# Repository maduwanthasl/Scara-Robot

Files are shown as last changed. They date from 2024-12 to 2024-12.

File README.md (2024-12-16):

# SCARA Robot (PRRR Configuration)

## 🌟 Overview  
This repository contains the design, build process, and control of a 4-DoF SCARA robot. The robot features a prismatic joint and three revolute joints (PRRR configuration) and is designed for precise pick-and-place tasks. It includes a functional GUI, real-time control, and an Arduino-based system for motor control.

<p align="center">
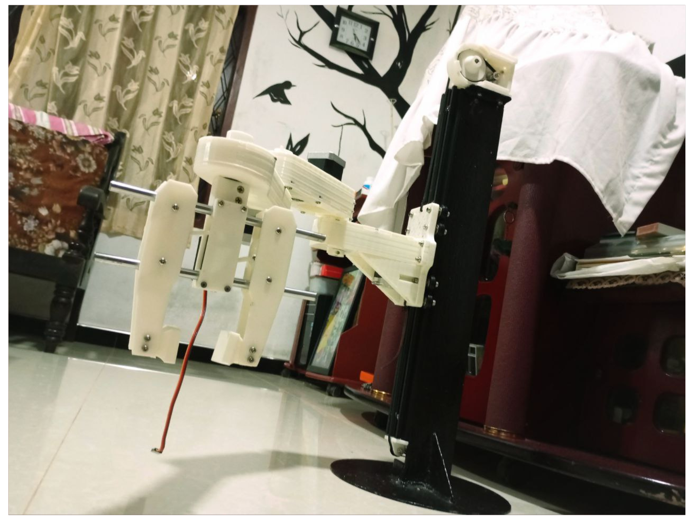
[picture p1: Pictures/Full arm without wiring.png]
  
</p>
<p align="center">
    <em>Figure 1: Final SCARA Robot</em>
</p>

---

## 📖 1. Introduction  
This project focuses on building and analyzing a **SCARA (PRRR)** robot arm with **4 Degrees of Freedom (DoF)**. It combines both kinematic analysis and practical implementation, including calculations for forward kinematics, inverse kinematics, and Jacobian analysis. The project culminates in a demonstration where the robot performs precise pick-and-place tasks and can **hold objects weighing up to 0.8 kg**.

**This SCARA robot is developed for industrial pick-and-place applications.**  
The manipulator consists of:  
- **A prismatic joint** for vertical motion.  
- **Three revolute joints** for horizontal movements and rotation.  
- **A gripper** for handling square and round objects.  

The robot is controlled using an Arduino Uno and stepper motors through a CNC shield. The GUI simplifies user interaction, making the robot versatile for various tasks.  

---

## 🎯 2. Final Outcome  
The SCARA robot successfully performs pick-and-place tasks with smooth motion and precise control.  

Video Preview (https://github.com/user-attachments/assets/54862c45-d594-4989-866d-df16e7200ece)

*Figure 2: Final Robot Outcome*  

---

## 🛠️ 3. Building Process  

### **3.1 Frame**  
In the SCARA robot building process, I first created a metal frame. I used a metal U-bar and a circular-shaped plate, soldering them as shown in Figure 3. To hold the Z-axis motor, I also soldered a plate. Afterward, I added screw holes to the grill and created two screw holes on the Z-holder plate. Additionally, I applied a coat of paint to resist metal corrosion.  

I also created screw holes in the U-bar to secure the aluminum extrusion. After that, I added a 40×20 aluminum extrusion to the U-bar using M5 20mm screws. This aluminum extrusion ensures smooth movement of the joints along the Z-axis.  

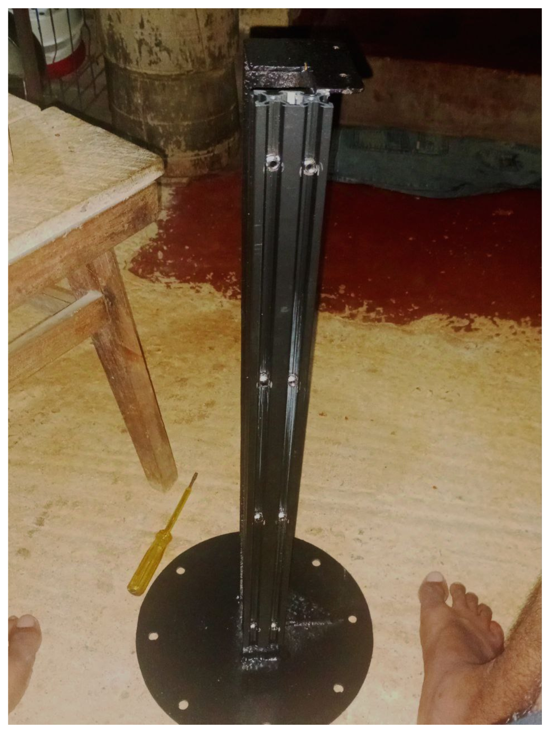
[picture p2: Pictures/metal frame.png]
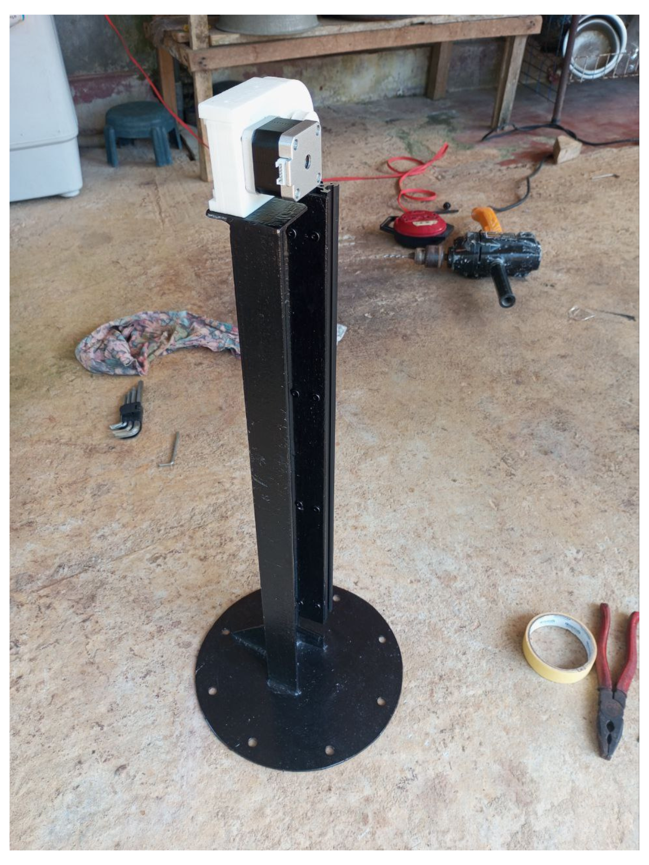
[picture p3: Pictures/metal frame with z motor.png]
|  |  |
|---|---|
| Metal frame | Metal frame with z motor|
<p align="center">
    <em>Figure 3: Metal Frame </em>
</p>

### **3.2 Joints**  

The joints of the SCARA robot are critical for achieving precise and smooth motion. Below is a detailed breakdown of the joint-building process.  

#### **3.2.1 3D Printed Parts**  
The main part of building this robot involved printing the 3D-printed components. Printing all the parts required over 100 hours using white PLA+ material. These parts included gears, mounting plates, and structural supports.  

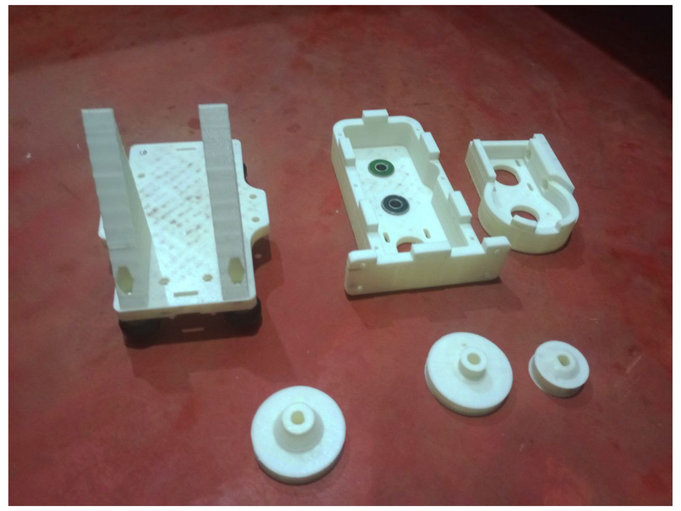
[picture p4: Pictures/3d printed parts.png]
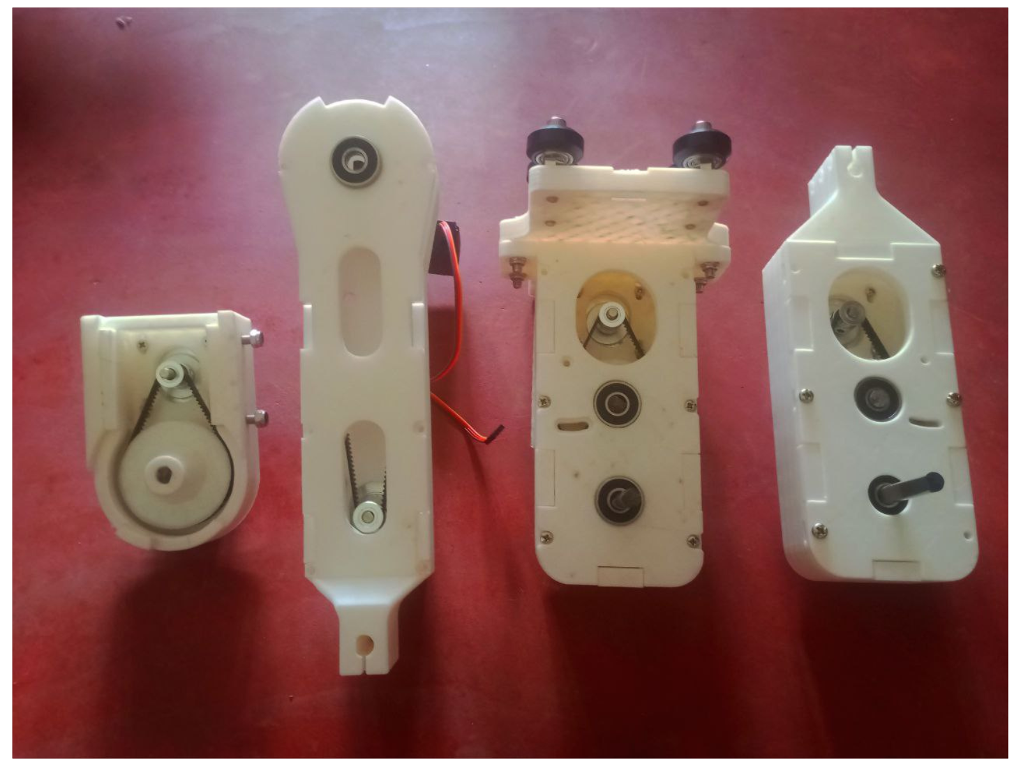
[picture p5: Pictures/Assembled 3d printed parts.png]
|  |  |
|---|---|
| Some 3D printed parts | Assembled Joints | 
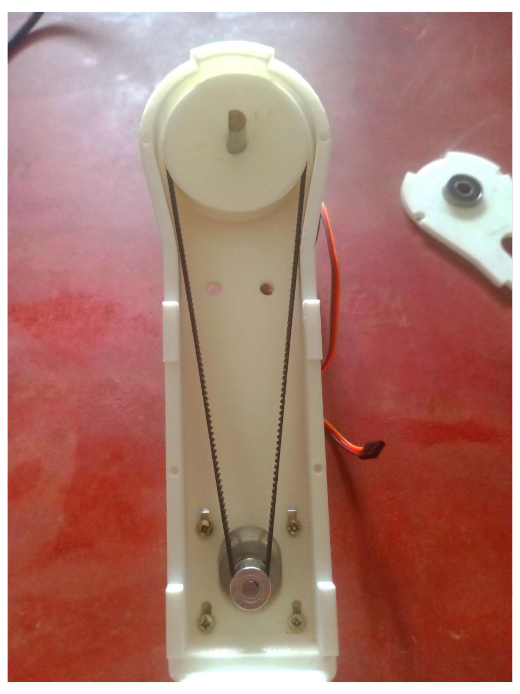
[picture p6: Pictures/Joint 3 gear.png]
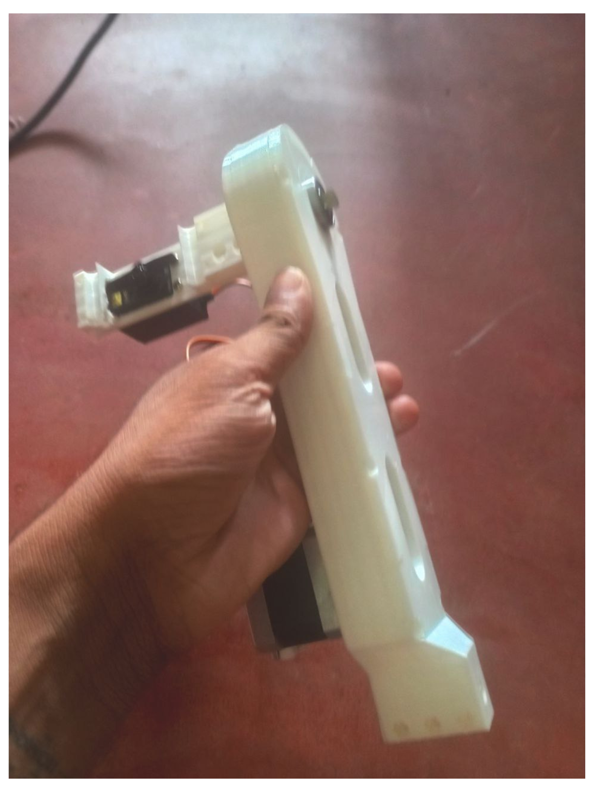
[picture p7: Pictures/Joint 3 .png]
|  | |
| Joint 3 Gears | Joint 3 Assembled |
<p align="center">
    <em>Figure 4: 3D printed parts </em>
</p>

#### **3.2.2 Linear Motion System**  
After printing the parts, I used 8mm diameter linear motion rods to construct the gear mechanism in the joints. To enhance torque, I incorporated 3D-printed gears into all joints. Most of the gear ratios were designed as 16:1, with some using a 4:1 ratio. These gears provided precise motion and controllable movements.  

To achieve smoother motion, I added 608RS bearings. For added friction with the gears, I modified small 8mm linear rods into a D shape using a grinder. By integrating suitable GT2 6mm closed-loop timing belts, the movement of the joints became more stable and reliable.  

Additionally, I added end-stop components made from 3D-printed parts. These help the robot identify when the arm has returned to its home position.  

#### **3.2.3 Challenges**  
The main challenge was ensuring that all belts were properly tightened and controllable to maintain smooth and precise motion throughout the joints.   

#### **3.2.4 Gripper Mechanism**  
The gripper is designed to handle objects of various shapes. It features a replaceable "hold cube" part that can be customized to grip different items. The gripper is powered by an MG 995 metal gear servo motor, which is well-suited for this type of application.  

#### **3.2.5 Sliding Mechanism**  
For the sliding mechanism, I attached a 3D-printed Z-plate to a **POM Wheel Pulley Kit**, which enabled smoother vertical motion. The Z-plate and pulley system significantly improved the performance of the prismatic joint.  

Video Preview (https://github.com/user-attachments/assets/a7ca6ed6-09e0-49c2-beae-47ccfda04f0f)

---

## 🔌 4. Wiring  

<p align="center">
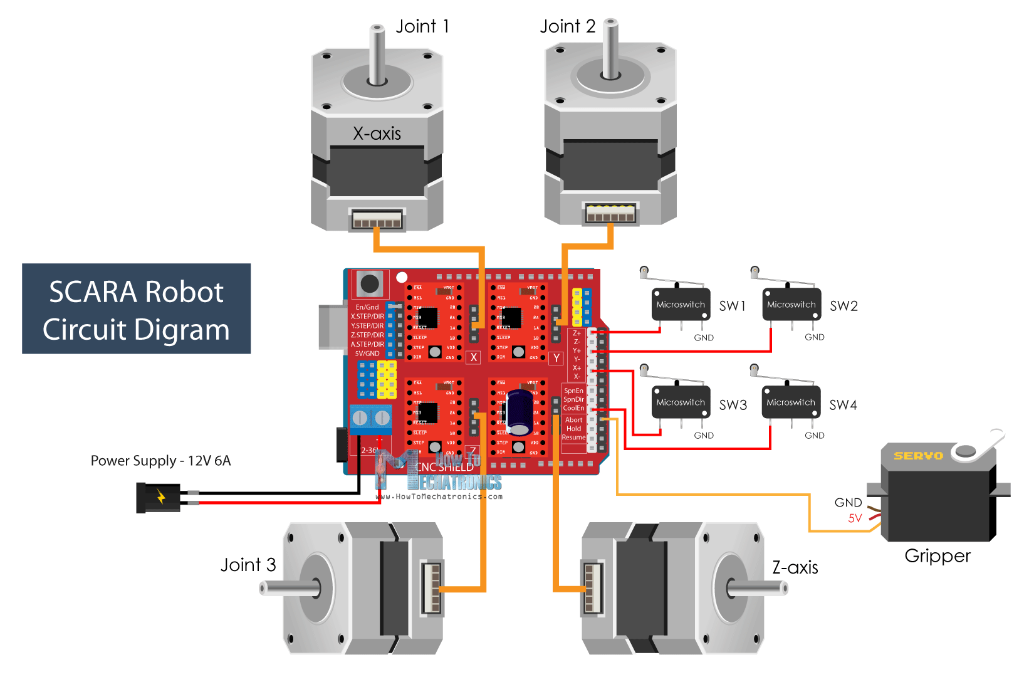
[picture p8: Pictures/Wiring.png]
  
</p>
<p align="center">
    <em>Figure 5: SCARA Robot main wiring diagram  </em>
</p>
<p align="center"> <em> Credit - how to mechatronics </em> </p>
 
The wiring connects stepper motors, the CNC shield, and the Arduino Uno. Here are the main considerations and steps followed:  

### **4.1 Motor Silence and Calibration**  
In wiring, I primarily focused on reducing motor noise. To achieve smooth motor operation, the current limit of the motor drivers was carefully adjusted. This calibration ensures precise motor activation. Setting an incorrect value can cause the motor drivers to overheat and potentially damage them. To further enhance motor precision, I adjusted the precision selector to 1/4 or 1/8 microstepping.

### **4.2 Connections and Testing**  
I connected the motor wiring as shown in the diagram and tested the connections with an oscilloscope and multimeter. Limit switches were placed at the corners of the joints' movement range to allow maximum rotational angles. After placing the limit switches, I assigned the pins for X+, Y+, Z+, and coolant functionalities.  

### **4.3 Servo Motor Powering**  
Since servo motors require a stable current, I initially tested them using the Arduino Uno with the CNC shield. However, the servo motor only received 3V from this setup, which was insufficient. To address this, I powered the servo motor separately using a 5V power supply.  

### **4.4 Power Supply Configuration**  
To power the entire system, which includes:  
- Four NEMA 17 stepper motors  
- Arduino Uno with CNC shield  
- Four motor drivers (DRV8825)  
- A servo motor  

I decided to use a 12V 10A power supply. A 12V 5A power supply would not have been sufficient to run all motors simultaneously.  

### **4.5 Cable Management**  
For clean and organized wiring, I used “Spiral Wire Wrapping Tube Cable Sleeves” and secured them with tie tags. This arrangement keeps the wires neat and minimizes clutter.  

### **4.6 Testing**  
To test all motors, I used simple Arduino code to verify their operation. This helped ensure that the motors, limit switches, and control pins were functioning as expected.  

### **4.7 Key Points**  
- **Shielded cables** were used for stepper motors to reduce electrical noise.  
- Correct polarity was ensured to avoid reversing motor directions.  
- The 12V DC power supply provided reliable power for the entire system.  

---

## 🏠 5. Homing Sequence
The homing sequence ensures that the robot starts from a known position:  

- The prismatic joint retracts to the lowest position.  
- Each revolute joint rotates to its home angle.  
- Limit switches provide feedback to confirm positions.  

As you can see in the video, the homing sequence begins with the gripper motor (joint 3). To determine the homing position, I used limit switches along with the following code:  

```cpp
void homing() {
  // Homing Stepper3
  while (digitalRead(limitSwitch3) != 1) {
    stepper3.setSpeed(-1100);
    stepper3.runSpeed();
    stepper3.setCurrentPosition(-1580); // When limit switch pressed set position to 0 steps
  }
  delay(20);

  stepper3.moveTo(0);
  while (stepper3.currentPosition() != 0) {
    stepper3.run();
  }

  // Homing Stepper2
  while (digitalRead(limitSwitch2) != 1) {
    stepper2.setSpeed(1300);
    stepper2.runSpeed();
    stepper2.setCurrentPosition(4350); // When limit switch pressed set position to -5440 steps
  }
  delay(20);

  stepper2.moveTo(0);
  while (stepper2.currentPosition() != 0) {
    stepper2.run();
  }

  // Homing Stepper1
  while (digitalRead(limitSwitch1) != 1) {
    stepper1.setSpeed(-1200);
    stepper1.runSpeed();
    stepper1.setCurrentPosition(-5000); // When limit switch pressed set position to 0 steps
  }
  delay(20);
  stepper1.moveTo(0);
  while (stepper1.currentPosition() != 0) {
    stepper1.run();
  }
  // Homing Stepper4
  while (digitalRead(limitSwitch4) != 1) {
    stepper4.setSpeed(-1500);
    stepper4.runSpeed();
    stepper4.setCurrentPosition(-8500); // When limit switch pressed set position to 0 steps
  }
  delay(20);
  // stepper4.moveTo(0);
  while (stepper4.currentPosition() != 0) {
    stepper4.run();
  }
}
```
**Homing** - https://github.com/maduwanthasl/Scara-Robot/blob/main/Videos/Homing%20Function/Homing%20Function.mp4

---

## 🧩 6. Pick and Place Application
The robot is programmed to pick objects from a defined source and place them in a target location.  

- Move to the pick position using the prismatic and revolute joints.  
- Grip the object using the servo-controlled gripper.  
- Transition to the target location and release the object.  

In the pick-and-place application, I saved 8 waypoints starting from its home position. Using the GUI, I configured these waypoints, which helped to better understand the movement of the joints and the gripper. After saving the waypoints and running the sequence, I achieved the following output:  

**Pick and Place Output** - https://github.com/maduwanthasl/Scara-Robot/blob/main/Videos/Pick%20and%20place/Pick%20and%20place.mp4

---

## 🖥️ 7. GUI  

<p align="center">
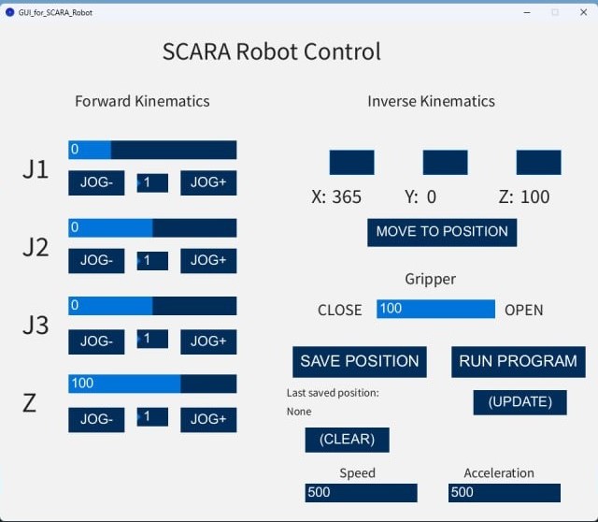
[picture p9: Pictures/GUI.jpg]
  
</p>

A user-friendly GUI is developed using **Processing**.  

### **Features**  
- Joint control via sliders and buttons.  
- Position control for end-effector coordinates.  
- Real-time feedback for joint angles and positions.  
- Gripper control for opening/closing actions.    

---

## 🛒 8. Bill of Materials  

---

### Purchase Details  
| **Buying Stores** | **Payable To** | **Invoice ** | **Date** |  
|---|---|---|---|
| Zenix | 11,890 | | |  
| Tronic LK | | | |  
| Asian | | | |  
| Unitech | | | |  

---

### Itemized List of Components  
| **Description** | **Qty** | **Unit Price** | **Total Price** |  
|---|---|---|---|
| 17HS4401 NEMA 17 Stepper with wire 0.4Nm (D Shaft 5mm) | 1 | Rs. 2,300.00 | Rs. 2,300.00 |  
| 2040 V Slot Aluminium Extrusion Profile Black 1m (Basic Quality) - Length (mm): 1000mm | 1 | Rs. 3,900.00 | Rs. 3,900.00 |  
| GT2 (Brown Anti-Slip Toothed Cloth, Rubber with Fiberglass) 6mm Open Timing Belt 1m | 2 | Rs. 350.00 | Rs. 700.00 |  
| GT2 16T 16 Teeth 5mm Bore 6mm Width Timing Pulley T16B5W6 - Color: Silver | 1 | Rs. 120.00 | Rs. 120.00 |  
| GT2 20T 20 Teeth 5mm Bore 6mm Width Timing Pulley T20B5W6 - Color: Silver | 3 | Rs. 120.00 | Rs. 360.00 |  
| GT2 20T 20 Teeth 8mm Bore 6mm Width Timing Pulley T20B8W6 - Color: Silver | 1 | Rs. 120.00 | Rs. 120.00 |  
| GT2 6mm Closed Loop Timing Belt 200mm | 5 | Rs. 190.00 | Rs. 950.00 |  
| GT2 6mm Closed Loop Timing Belt 400mm | 2 | Rs. 280.00 | Rs. 560.00 |  
| Openbuilds (Type A2 with Eccentric Spacer) POM Wheel Pulley Kit for 2020 V Slot Aluminum Profiles | 8 | Rs. 360.00 | Rs. 2,880.00 |  
| 17HS4401 NEMA 17 Stepper with wire 0.4Nm (D Shaft 5mm) | 3 | Rs. 2,300.00 | Rs. 4,600.00 |  
| CNC Shield V3 Expansion Board for Engraving Machine | 1 | Rs. 490.00 | Rs. 490.00 |  
| 8mm Insulated Braided Sleeve High Temperature Tube 1m | 1 | Rs. 120.00 | Rs. 120.00 |  
| GT2 16T 16 Teeth 5mm Bore 10mm Width Timing Pulley T16B5W10 | 1 | Rs. 160.00 | Rs. 160.00 |  
| GT2 20T (With Teeth) 5mm Bore 6mm Width Idler Timing Pulley B5W6 - Color: Black | 1 | Rs. 260.00 | Rs. 260.00 |  
| GT2 16T 16 Teeth 5mm Bore 6mm Width Timing Pulley T16B5W6 - Color: Silver | 2 | Rs. 120.00 | Rs. 240.00 |  
| Arduino UNO Original Development | 1 | Rs. 2,510.00 | Rs. 2,510.00 |  
| DRV8825 Stepper Motor Driver for CNC 3D Printer | 4 | Rs. 520.00 | Rs. 2,080.00 |  
| Cable Tie 15-inch 100 pcs | 1 | Rs. 300.00 | Rs. 300.00 |  
| M5 35mm Stainless Steel Hex Flat Socket Head Countersunk Screw | 12 | Rs. 70.00 | Rs. 840.00 |  
| M5 16mm Stainless Steel Hex Flat Socket Head Countersunk Screw | 6 | Rs. 40.00 | Rs. 240.00 |  
| M3 20mm Countersunk Bolt | 12 | Rs. 5.00 | Rs. 60.00 |  
| M4 15mm Countersunk Bolt | 18 | Rs. 10.00 | Rs. 180.00 |  
| Black 10mm 1 Bag (13.5m/Bag) Spiral Wire Wrapping Tube Cable Sleeves | 1 | Rs. 800.00 | Rs. 800.00 |  
| 12V 10A Power Supply | 1 | Rs. 2,200.00 | Rs. 2,200.00 |  
| Jumper Cables | 1 | Rs. 140.00 | Rs. 140.00 | 
| Bearing 608-RS			 | 15	 | Rs.400	 | Rs.6,000.00 |
| 8mm Leaniar Rob			 |1	 | $1,500	| $1,500.00 |
| Other | 1 | Rs. 2,000.00 | Rs. 2,000.00 |  

---

### **Total Cost**  
| **Subtotal** | Rs. 36,610.00 |  
|---|---|
| **Adjustments** | Rs. 0.00 |  
| **Final Total** | **Rs. 36,610.00** |  

---

## 🖨️ 9. 3D Printed Parts

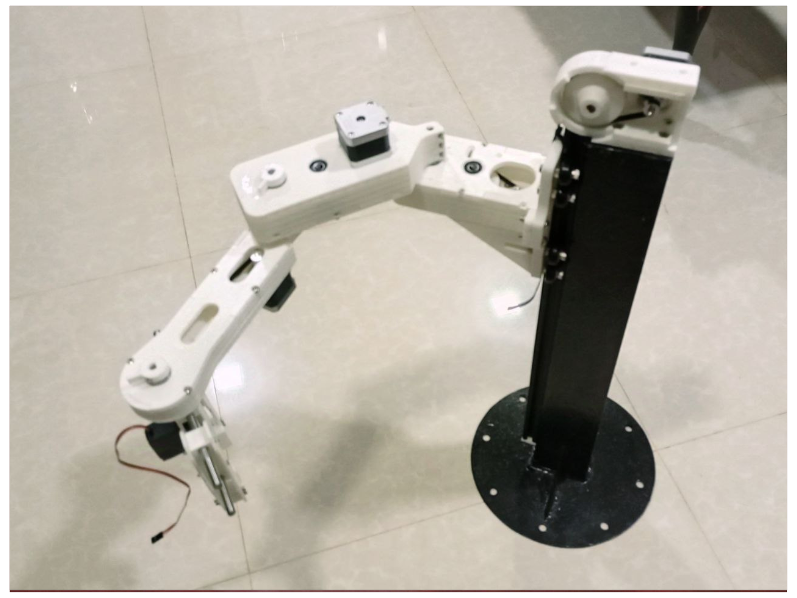
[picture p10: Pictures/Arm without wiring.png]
| pic 6 (2) |  |
|---|---|
<p align="center">
    <em>Figure 6: ARM without wiring </em>
</p>

The robot's design relies heavily on 3D-printed components, with over 100 hours of printing time invested to produce these parts. Each part was carefully designed to ensure functionality and precision:  

- **Gears**: Over seven different types of gears were printed to enable precise torque transfer and smooth motion across the joints.  
- **Link Components**: Critical parts for Link 1, Link 2, and Link 3 were printed to form the main structure of the robotic arm, allowing for stable and accurate joint movements.  
- **Z Holder**: This component supports the prismatic joint, ensuring reliable vertical motion and alignment.  
- **Limit Switch Contactors**: Custom 3D-printed parts that interact with limit switches to facilitate homing and accurate position detection.  
- **Gripper Mechanism**: Includes the gripping claws and structural supports necessary for securely holding objects during operation.  
- **Support Structures**: Temporary structures were printed alongside the main components to maintain the integrity of complex shapes during the printing process.  

These parts were printed using PLA+ material for durability and dimensional accuracy. All STL files are organized and available in the `/3D-Printed-Parts` folder for easy access and replication.  

---

## 🔗 10. Code Explanation
The robot is programmed using Arduino Uno, with future plans to transition to AVR register-based programming for enhanced control. The key programming aspects include:  

- **Forward Kinematics**: Calculates the end-effector position based on joint values, ensuring precise movement to desired coordinates.  
- **Inverse Kinematics**: Determines joint angles for a given position, enabling accurate trajectory planning for the robot arm.  
- **DH Table and Jacobian Matrix**: The Denavit-Hartenberg (DH) parameters were derived to construct the transformation matrix, while the manipulator Jacobian was calculated to analyze joint velocities and forces.  
- **Control Algorithms**: Implements control for stepper motors, including speed adjustments and precise motion handling.  
- **Gripper Control**: Manages the servo-controlled gripper to open and close efficiently based on commands.  

To facilitate communication between the computer and the Arduino Uno, serial communication was established at a baud rate of 115200. This allows for easy command input and real-time control without needing to manually alter the code for each operation.  

Future iterations will focus on optimizing the code and exploring advanced microcontroller programming techniques for better performance.  

---

## 🎛️  11. Robot Details and Calculations

### **11.1 Link Dimensions and Specifications**  
The SCARA robot has **4 Degrees of Freedom (DoF)** with a **PRRR joint configuration**.  

**Link Dimensions**:  
- a1 = 160mm — Link 1 length  
- a2 = 220mm — Link 2 length  
- a3 = 202mm — Link 3 length  
- d4 = 580mm — Prismatic joint length  

### **11.2 Coordinate Frame Assignment**  
The following figure illustrates the coordinate frame assignment for the SCARA PRRR robot, adhering to the Denavit-Hartenberg (DH) convention:  

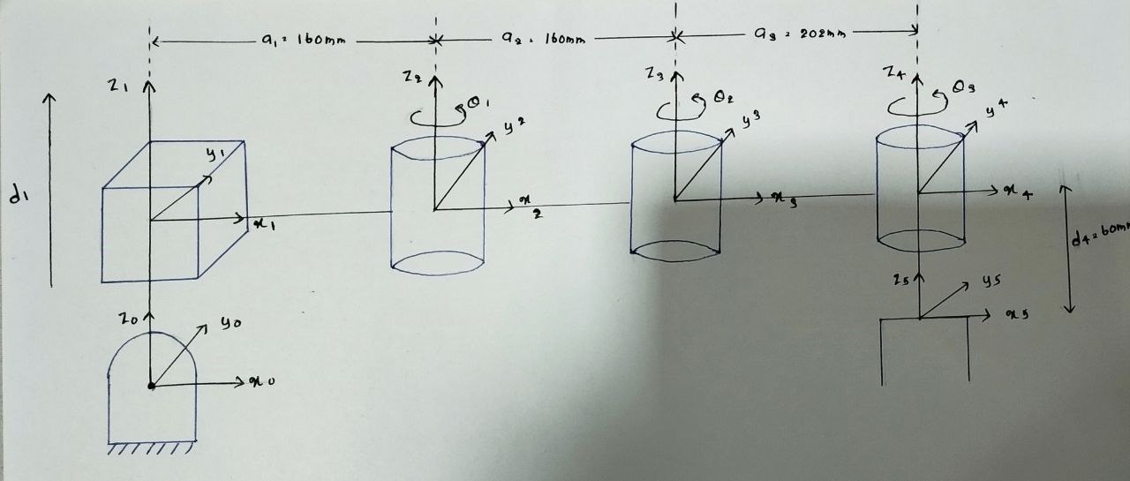
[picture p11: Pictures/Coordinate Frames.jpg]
Coordinate Frame Assignment
  

### **11.3 DH Table**  
The table below summarizes the DH parameters for the SCARA PRRR robot:  

| **Joint (i)** | **aᵢ (mm)** | **αᵢ (°)** | **dᵢ (mm)** | **θᵢ (°)** |
|---|---|---|---|---|
| 1 (Prismatic) | 0 | 0 | d₁ (variable) | 0 |
| 2 (Revolute) | 160 | 0 | 0 | θ₁ (variable) |
| 3 (Revolute) | 160 | 0 | 0 | θ₂ (variable) |
| 4 (Revolute) | 202 | 0 | 0 | θ₃ (variable) |
| 5 | 0 | 0 | 580 | 0 |

### **11.4Forward Kinematics**

Forward kinematics calculates the position and orientation of the end-effector based on the joint angles and link lengths. Using Denavit-Hartenberg (DH) parameters, we define the transformation matrix for each joint. The transformation matrix is:

<p align="center">
  SCARA Robot
</p>
By multiplying the individual transformation matrices from base to end-effector, we get the final transformation matrix T . This matrix provides the position (x, y, z) and the orientation of the end-effector. The angles θ1, θ2, and θ3 are used to determine the robot’s orientation in space.

<p align="center">
  SCARA Robot
</p>

<p align="center">
  SCARA Robot
</p>

The Jacobian is derived using the partial derivatives of the forward kinematics equations.  

### **11.5Manipulator Jacobian Matrix**
The Jacobian matrix relates joint velocities to end-effector velocities. It is essential for analyzing the robot’s motion and controlling its speed and acceleration. For a PRRR manipulator, the Jacobianmatrix has two parts:

- Linear Velocity: The part of the Jacobian that maps joint velocities to linear velocities of the end-effector. It involves the cross product between the joint axes and the position vector.
- Angular Velocity: The part that maps joint velocities to angular velocities.

The Jacobian for the SCARA robot is given by:

<p align="center">
  SCARA Robot
</p>

---

## 📶 12. Gallery  
The gallery showcases the various stages of the robot's development, including 3D-printed parts, wiring, assembly, and testing.

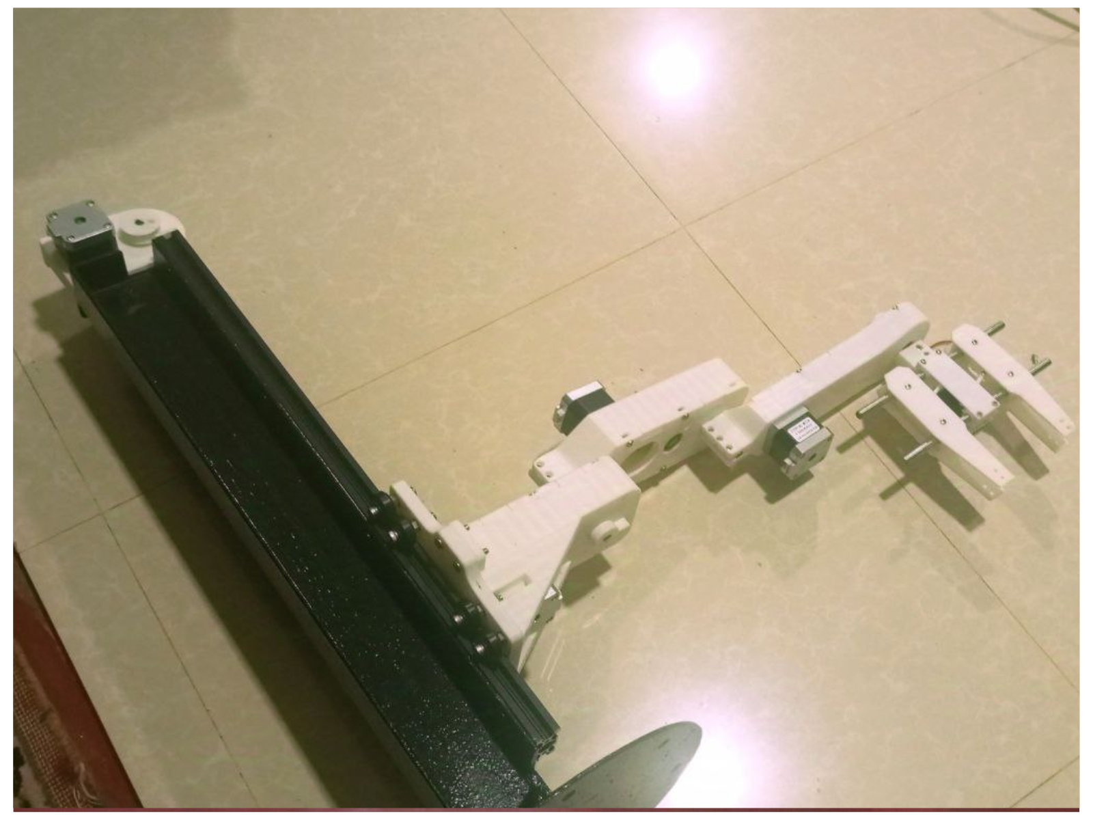
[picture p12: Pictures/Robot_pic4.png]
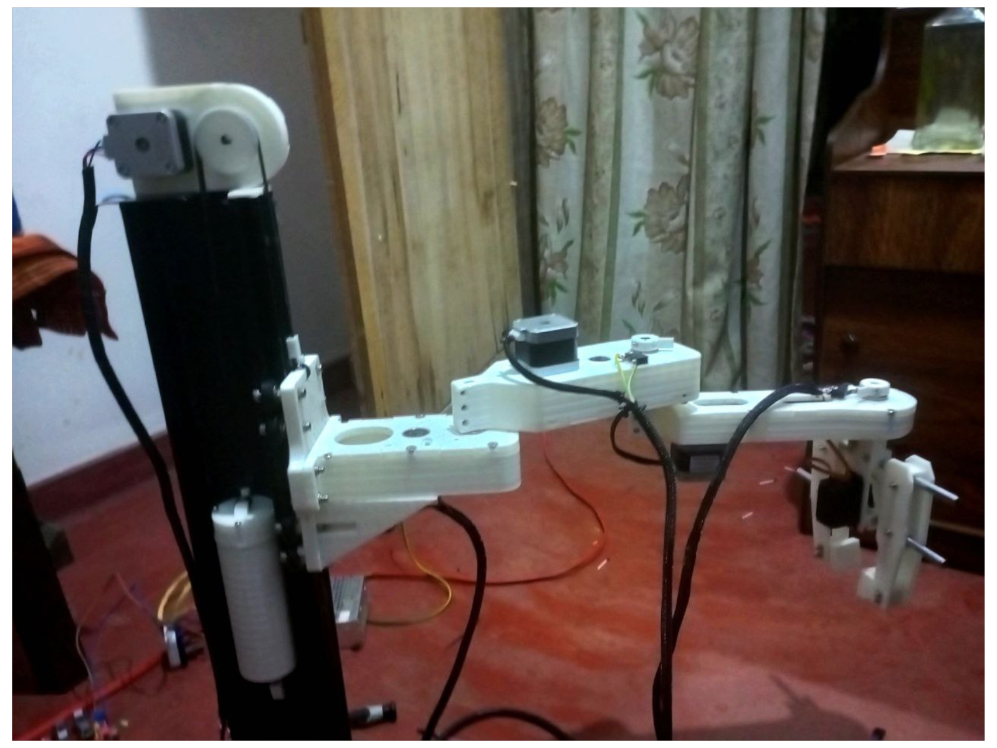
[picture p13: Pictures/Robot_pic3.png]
|  |  |
|---|---|
| Adding All Joints | Adding wiring | 
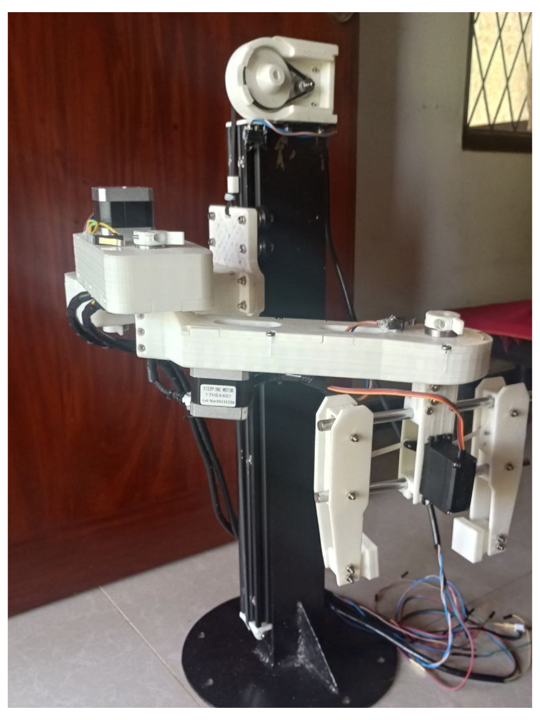
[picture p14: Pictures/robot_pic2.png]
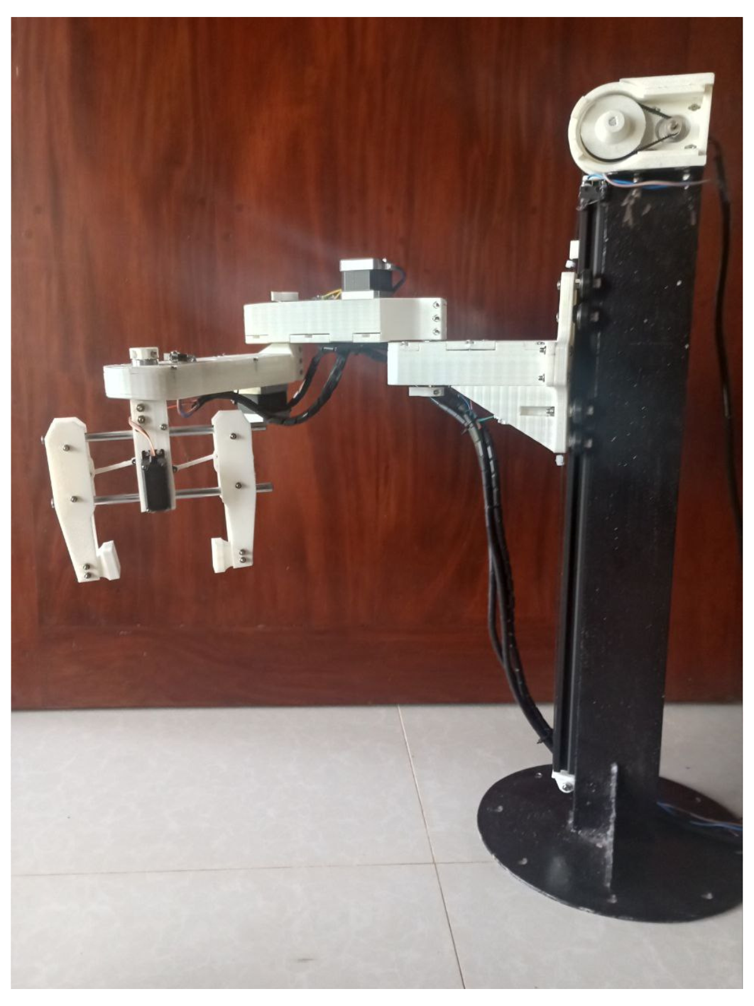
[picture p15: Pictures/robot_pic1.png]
|  | |
| Angle 1 | Angle 2 |
<p align="center">
    <em>Figure 7: Build Journey</em>
</p>

---
## 🤖 13. References  
- SCARA Robot Design Basics: [Link](https://en.wikipedia.org/wiki/SCARA)  
- Arduino CNC Shield Documentation: [Link](https://www.aranacorp.com/en/using-an-arduino-cnc-shield-v3)  
- Processing Language for GUI: [Link](https://howtomechatronics.com/projects/scara-robot-how-to-build-your-own-arduino-based-robot)
- Scara Robot 3D Printed Parts: [Link](https://github.com/IVProjects/Engineering_Projects/tree/main/ProjectFiles/SCARA%20Robot)
  
---

Feel free to raise issues or contribute improvements to this project!

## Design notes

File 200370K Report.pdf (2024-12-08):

Department of Electronic & Telecommunication Engineering, University of Moratuwa, Sri Lanka.

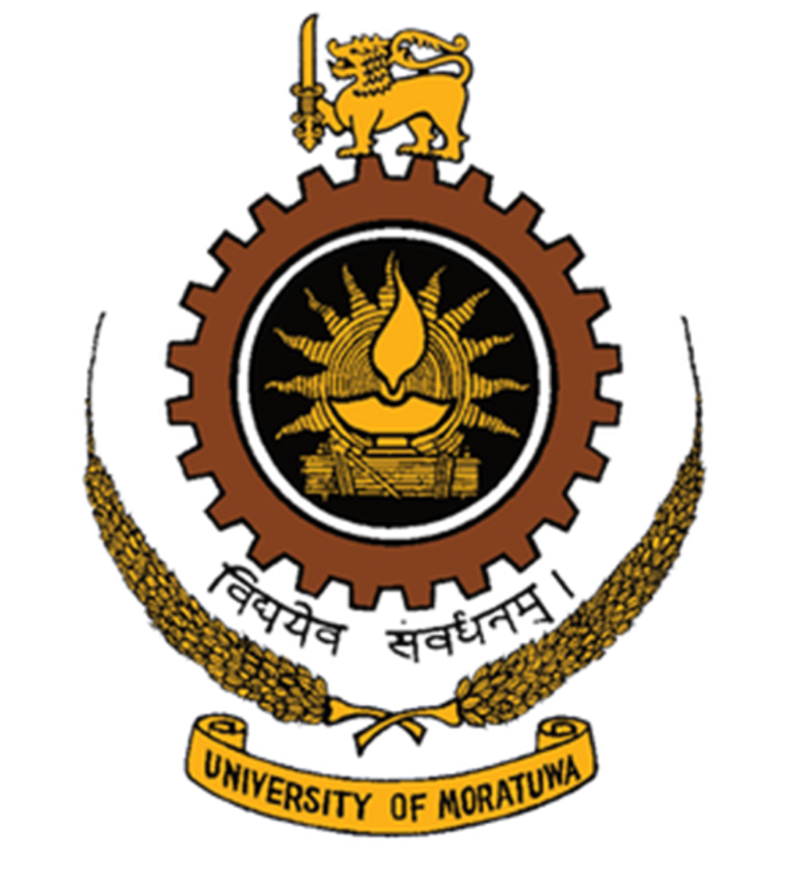
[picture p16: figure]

# Robotics Mini Project Kinematic Analysis of a Robot Arm

Maduwantha L.H.H | 200370K

## Summarizing the analysis - Report In21 S5 EN3563 - Robotics

08th December 2024

EN 2160 Electronics Design Realization

## Introduction

This mini-project focuses on the kinematic analysis of a SCARA robot with four degrees of freedom (DoF). The robot has a prismatic joint (for vertical movement) and three revolute joints (for horizontal rotation), allowing it to perform pick-and-place tasks. A functional gripper is included to handle round and square objects.

Analysis

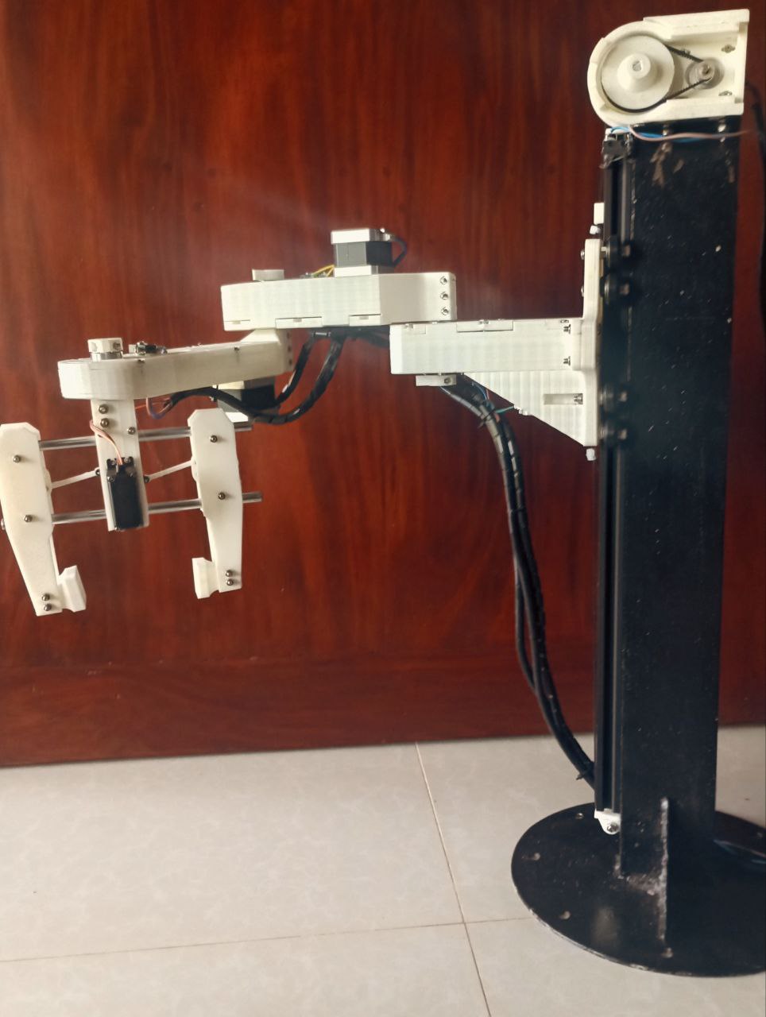
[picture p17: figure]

The analysis includes:
- Deriving Denavit-Hartenberg (DH) parameters.
- Calculating forward and inverse kinematics.
- Deriving the Jacobian matrix.

Control and Payload

The robot is controlled using an Arduino Uno and stepper motors via a CNC shield. It has a maximum payload of 0.8 kg.

1

## Robot Design and DH Parameters

Robot Configuration

The robot arm consists of the following links and joints:
- a1 = 160 mm, a2 = 160 mm, a3 = 202 mm: These are the link lengths between the revolute joints.
- d1 (variable): Vertical movement of the prismatic joint.
- d4 = 60 mm: Constant offset for the final joint.
- θ1, θ2, θ3: The joint angles that control the robot’s movement in the horizontal plane.

Scara Robot - Coordinate Frame assignment


Denavit-Hartenberg Parameters

The Denavit-Hartenberg (DH) parameters describe the geometry of the robot arm through a systematic convention. The table below shows the DH parameters for the SCARA robot:

Joint (i) | ai (mm) | αi | di (mm) | θi
1 (Prismatic) | 0 | 0 | d1 (variable) | 0
2 (Revolute) | 160 | 0 | 0 | θ1 (variable)
3 (Revolute) | 160 | 0 | 0 | θ2 (variable)
4 (Revolute) | 202 | 0 | 0 | θ3 (variable)
5 | 0 | 0 | 60 | 0

Table 1: DH Parameters for the SCARA Robot

This DH table is crucial for calculating the forward and inverse kinematics.

## Forward Kinematics

Forward kinematics calculates the position and orientation of the end-effector based on the joint angles and link lengths. Using Denavit-Hartenberg (DH) parameters, we define the transformation matrix for each joint. The transformation matrix is:

2

T

i
i−1 =

cos θi | − sin θi cos αi | sin θi sin αi | ai cos θi
sin θi | cos θi cos αi | − cos θi sin αi | ai sin θi
0 | sin αi | cos αi | di
0 | 0 | 0 | 1

By multiplying the individual transformation matrices from base to end-effector, we get the final transformation matrix T

4/0. This matrix provides the position (x, y, z) and the orientation of the end-effector. The angles θ1, θ2, and θ3 are used to determine the robot’s orientation in space.

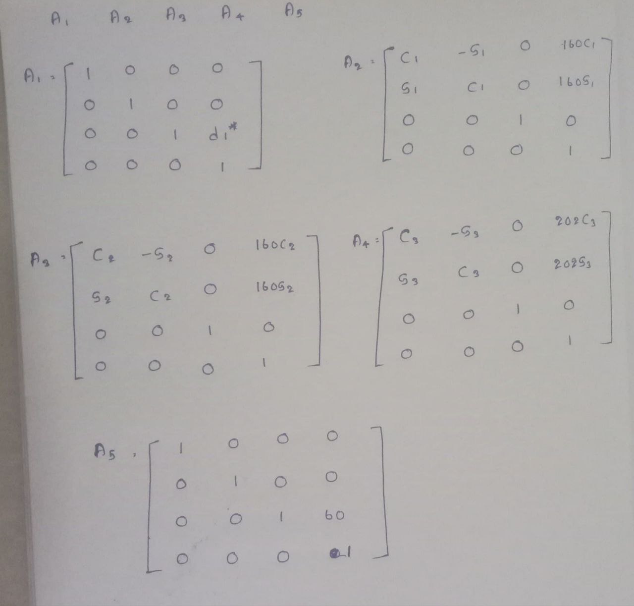
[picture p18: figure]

End-Effector Position

Using the link lengths and joint angles, the position of the end-effector is calculated as:

x = a1 sin(90◦
) + a2 cos θ1 + a3 cos(θ1 + θ2)

x = 160 + 160 cos θ1 + 202 cos(θ1 + θ2)

y = a1 cos(90◦
) + a2 sin θ1 + a3 sin(θ1 + θ2)

y = 0 + 160 sin θ1 + 202 sin(θ1 + θ2)

z = z0 + d1

## Inverse Kinematics

Inverse kinematics is the process of solving for the joint variables (θ1, θ2, θ3, d0) given a desired position and orientation of the end-effector. For the SCARA robot, the inverse kinematics is separated into two primary steps:

3

Step 1: Solve for θ1, θ2, θ3

Using the planar geometry of the robot, we can calculate the joint angles. The horizontal position of the end-effector is given by:

x = a1 + a2 cos(θ1) + a3 cos(θ1 + θ2)

y = a2 sin(θ1) + a3 sin(θ1 + θ2)

The law of cosines is applied to solve for θ2 and θ3 iteratively:

cos θ2 =

r

2 − a

2
2 − a

2
3
2a3a2

Once θ2 is computed, θ1 is found by solving for the orientation of the base using inverse trigonometry:
θ1 = arctan y
x

− arctan
a3 sin θ2
a2 + a3 cos θ2

Finally, θ3 is derived by using the desired end-effector orientation.

Step 2: Solve for d0

The vertical position is determined by the prismatic joint:

d1 = z − d4

## Jacobian Matrix

The Jacobian matrix relates joint velocities to end-effector velocities. It is essential for analyzing the robot’s motion and controlling its speed and acceleration. For a PRRR manipulator, the Jacobian matrix has two parts:

- Linear Velocity: The part of the Jacobian that maps joint velocities to linear velocities of the end-effector. It involves the cross product between the joint axes and the position vector.
- Angular Velocity: The part that maps joint velocities to angular velocities.

The Jacobian for the SCARA robot is given by:

J =

Jv
Jω

Where:

- Jv is the linear velocity Jacobian, accounting for the prismatic and revolute joints.
- Jω is the angular velocity Jacobian, accounting for revolute joints.

J =

(z

o
0

) z

o
1
- (t

o
4 − ti) z

o
2
- (t

o
4 − t

o
2

) z

o
3
- (t4 − t

o
3

)
0 | z

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
0 J12 | J13 | J14
0 J22 | J23 | J24
1 J32 | J33 | J34
0 | 0 | 0 | 0
0 | 0 | 0 | 0
0 | 1 | 1 | 1

4

## Graphical User Interface (GUI)

The GUI allows users to control the SCARA robot with ease. It was developed using Processing and communicates with the robot via an Arduino Uno.


Key Features

- Joint Control:
Sliders and buttons enable precise movement of the robot’s joints (θ1, θ2, θ3, d1).
- Position Control:
Users can input the desired end-effector positions, and the robot calculates the corresponding joint angles.
- Gripper Control:
Buttons are provided to open and close the gripper for handling objects.
- Real-time Feedback:
The interface displays the current position and status of the robot in real time.

## Reference

- IVProjects GitHub (https://github.com/IVProjects) - *Engineering Projects*

5

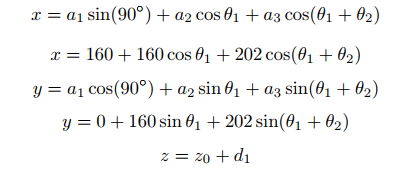
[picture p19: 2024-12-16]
Pictures/Forard kinematics.png

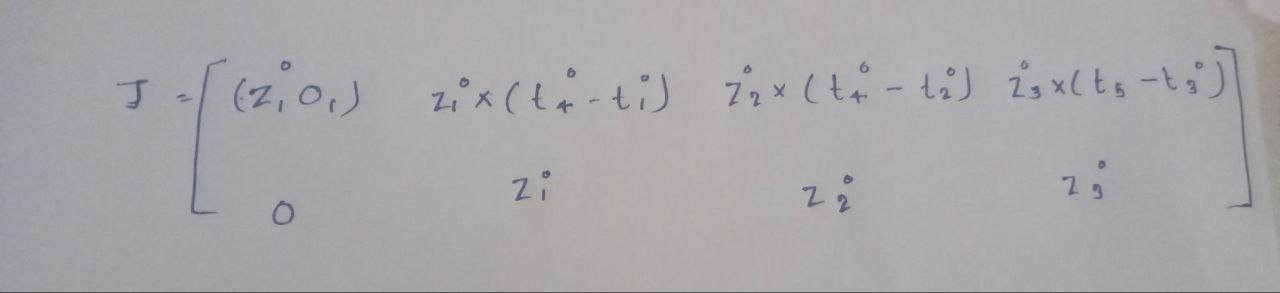
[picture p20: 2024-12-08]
Pictures/Manipulator Jacobian.jpg

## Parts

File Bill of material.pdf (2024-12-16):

# Scara Robot Design

Hirusha Madhuwantha
(+94) 741270399

# Bill of Materials

Submitted on 09/10/2024

Buying stores | Payable to | Invoice # | Date
zenix | 11,890 | #IN002095 | 2024-09-09

tronic lk

Asian

Unitech

Description | Qty | Unit price | Total price

17HS4401 NEMA 17 Stepper with wire 0.4Nm (D Shaft 5mm) 1 $2,300.00 $2,300.00

2040 V Slot Aluminium Extrusion Profile Black 1m (Basic Quality) -$3,900.00 Length (mm) : 1000mm 1 $3,900.00

GT2 (Brown Anti-Slip Toothed Cloth, Rubber with Fiberglass) 6mm Open 2 $700.00 $350.00 Timing Belt 1m

GT2 16T 16 Teeth 5mm Bore 6mm $120.00 Width Timing Pulley T16B5W6 -Color : Silver 1 $120.00

GT2 20T 20 Teeth 5mm Bore 6mm
Width Timing Pulley T20B5W6 -
Color : Silver | 3 | $120.00

$360.00

GT2 20T 20 Teeth 8mm Bore 6mm $120.00 Width Timing Pulley T20B8W6 -1 Color : Silver $120.00

GT2 6mm Closed Loop Timing Belt 200mm 5 $190.00 $950.00

GT2 6mm Closed Loop Timing Belt 400mm 2 $280.00 $560.00

Openbuilds (Type A2 with Eccentric Spacer) POM Wheel Pulley Kit for 2020 V Slot Aluminum Profiles 8 $360.00 $2,880.00

17HS4401 NEMA 17 Stepper with wire 0.4Nm (D Shaft 5mm) 3 $2,300.00 $4,600.00

CNC Shield V3 Expansion Board for Engraving Machine 1 $490.00 $490.00

8mm Insulated Braided Sleeve High Temperature Tube 1m 1 $120.00 $120.00

GT2 16T 16 Teeth 5mm Bore 10mm Width Timing Pulley T16B5W10 1 $160.00 $160.00

GT2 20T (With Teeth) 5mm Bore 6mm Width Idler Timing Pulley B5W6 - Color: Black 1 $260.00 $260.00

GT2 16T 16 Teeth 5mm Bore 6mm Width Timing Pulley T16B5W6 - Color: Silver 2 $120.00 $240.00

Arduino UNO Original Development | 1 $2,510.00 $2,510.00
DRV8825 Stepper Motor Driver for CNC 3D Printer | 4 | $520.00 | $2,080.00
Cable Tie 15-inch 100 pics | 1 $300.00 $300.00
M5 35mm Stainless Steel Hex Flat Socket Head Countersunk Screw 12 M5 16mm Stainless Steel Hex Flat Socket Head Countersunk Screw 6 M3 20mm Countersunk Bolt M4 15mm Countersunk Bolt Black 10mm 1 Bag (13.5m/Bag) Spiral Wire Wrapping Tube Cable Sleeves 1 | $70 $40 12 $5 18 $10 $800 | $840.00 $240.00 $60.00 $180.00 $800.00
12V 10A power supply 1 $2,200 | | $2,200.00

Jumper cables

| 1 | $140 | $140.00
Bearing 608-RS | 15 | $400 | $6,000.00

8mm Leaniar Rob

| 1 | $1,500 | $1,500.00
Other | 1 | $2,000 | $2,000.00
Notes: | | Subtotal | $36,610.00
| | Adjustments | $0.00
$36,610.00

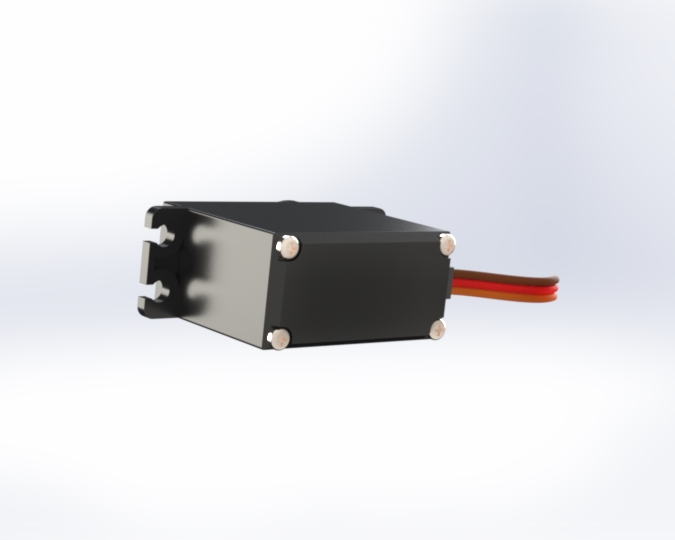
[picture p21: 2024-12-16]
3D printed parts/mg995-servo-3.snapshot.4/MG995 2.jpg

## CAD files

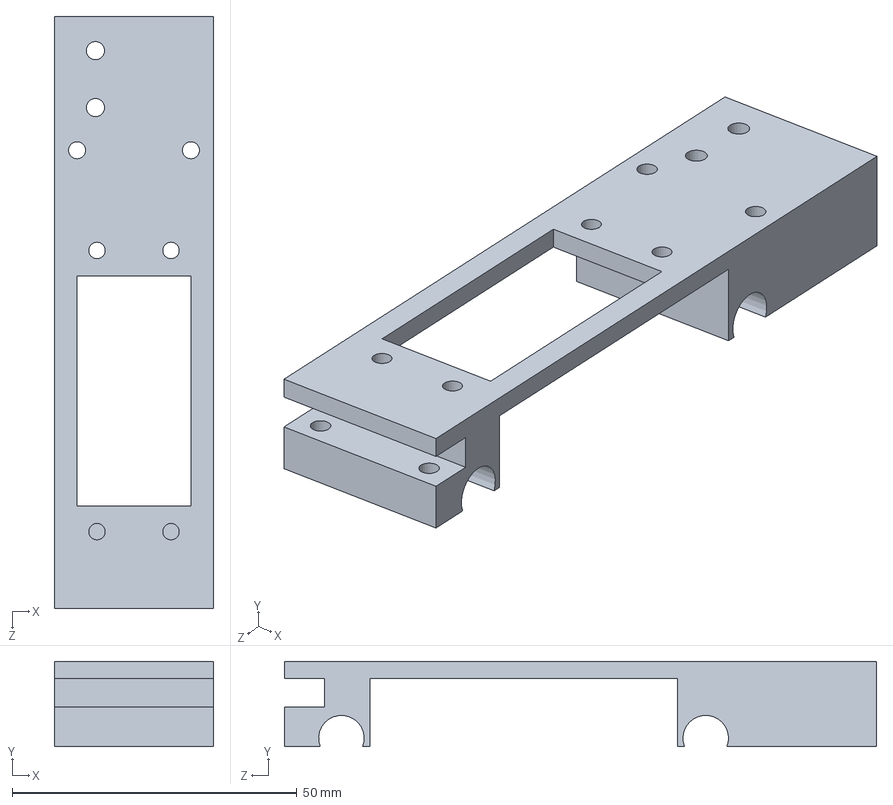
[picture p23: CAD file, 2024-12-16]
3D printed parts/gripper_main.SLDPRT
28.0 x 15.0 x 104.0 mm

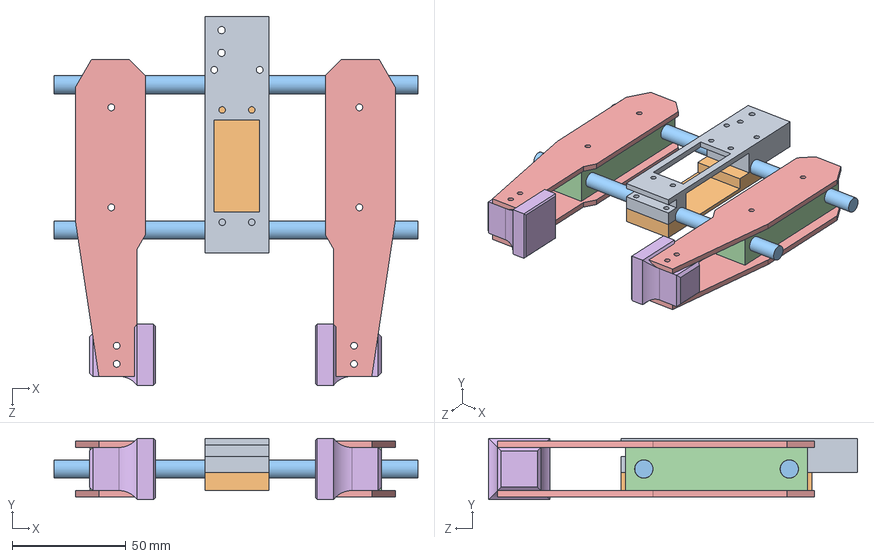
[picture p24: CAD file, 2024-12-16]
3D printed parts/gripper_assembly.SLDASM
160.0 x 27.0 x 162.3 mm
gripper_main
top
8mm rod x 2
cube_part x 2
sideplate x 4
holdcube x 2

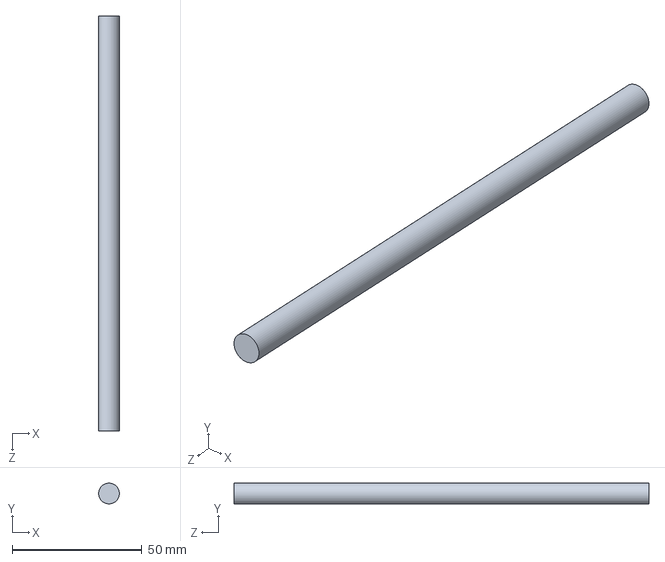
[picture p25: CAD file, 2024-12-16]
3D printed parts/8mm rod.SLDPRT
8.00 x 8.00 x 160.0 mm

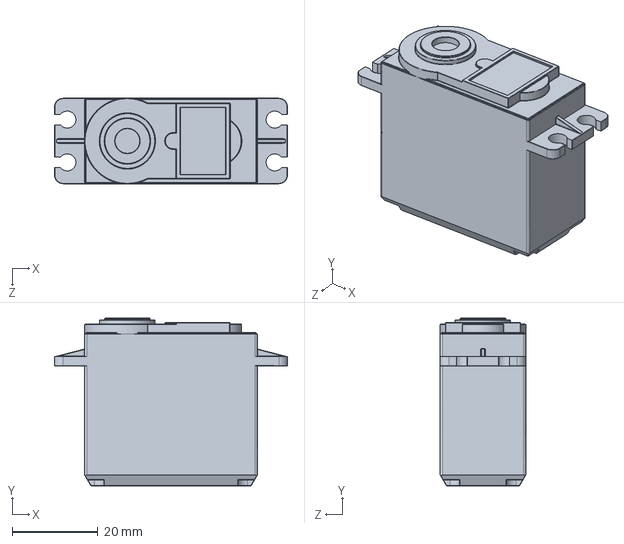
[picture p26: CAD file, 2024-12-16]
3D printed parts/mg995-servo-3.snapshot.4/MG995.SLDPRT
54.5 x 39.2 x 20.0 mm

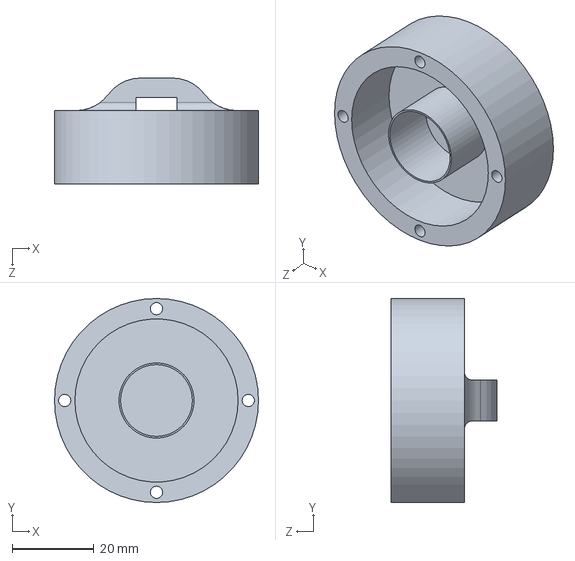
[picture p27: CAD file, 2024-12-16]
3D printed parts/New Gripper to any object/weight_holder_top.SLDPRT
50.0 x 50.0 x 26.0 mm

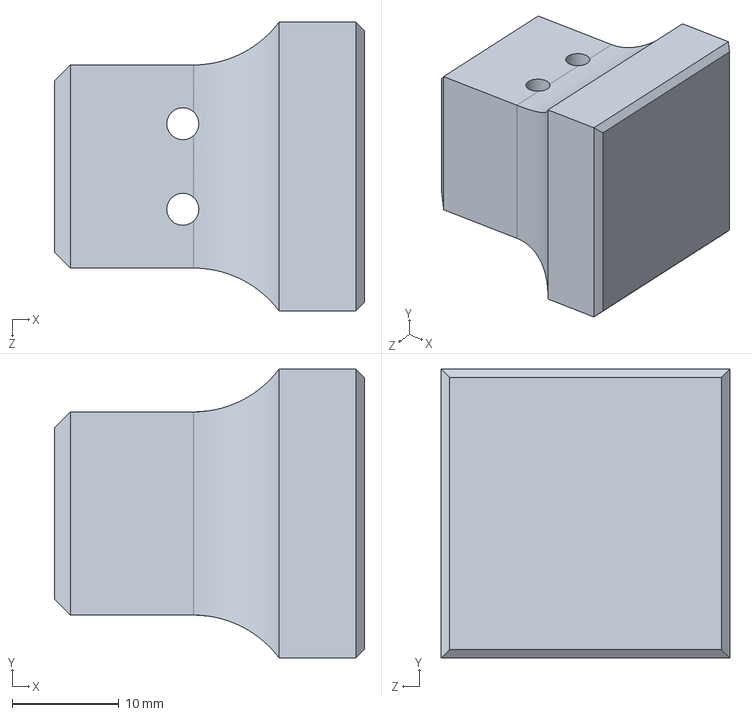
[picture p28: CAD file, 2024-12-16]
3D printed parts/New Gripper to any object/holdcube.SLDPRT
29.0 x 27.0 x 27.0 mm

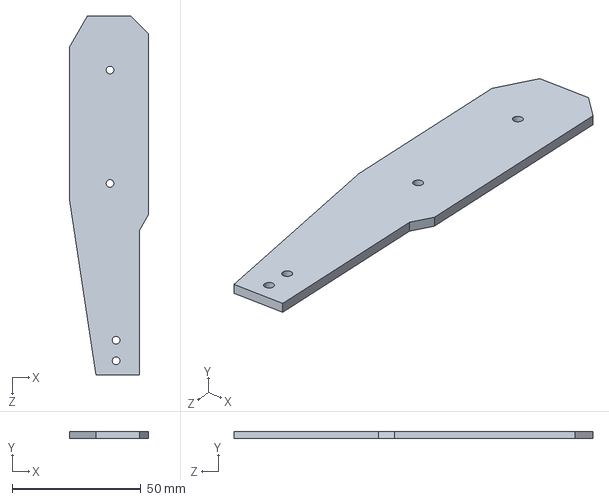
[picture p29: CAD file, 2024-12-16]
3D printed parts/sideplate.SLDPRT
30.8 x 2.80 x 139.3 mm

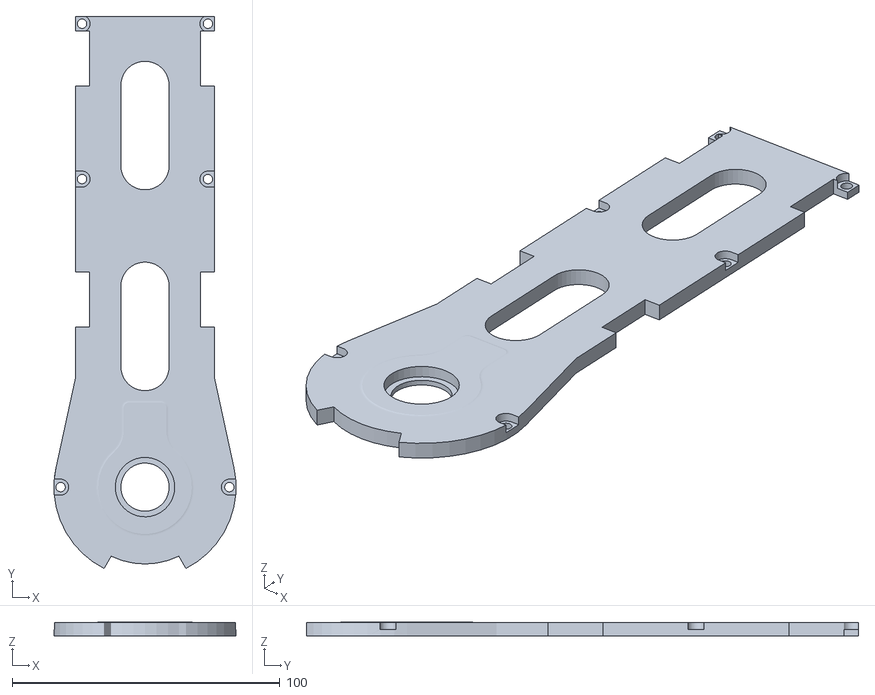
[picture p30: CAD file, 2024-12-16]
3D printed parts/5to1LastSegment_top.STL
67.8 x 206.1 x 5.10

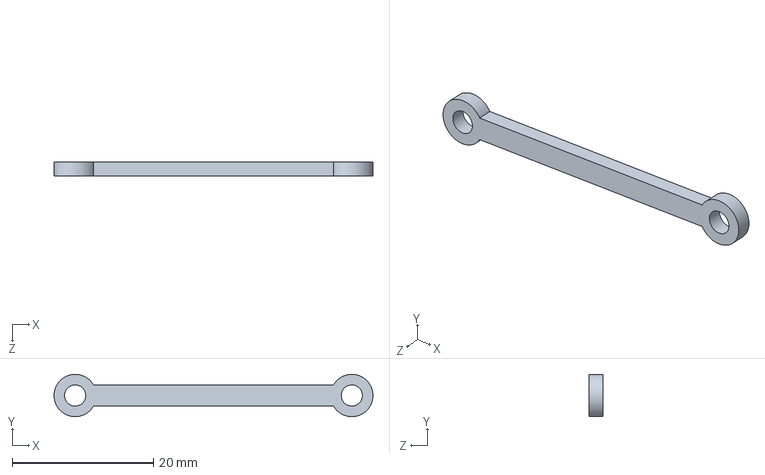
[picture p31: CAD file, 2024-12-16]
3D printed parts/New Gripper to any object/line_seg.SLDPRT
45.2 x 6.00 x 2.00 mm

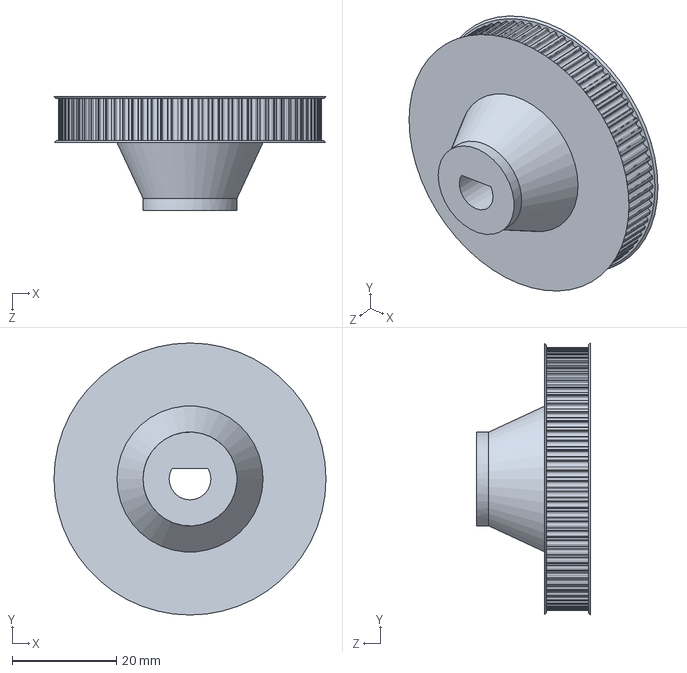
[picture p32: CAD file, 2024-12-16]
3D printed parts/ExtendedGT2_80t_TimingBeltPulley.SLDPRT
52.1 x 52.1 x 21.8 mm

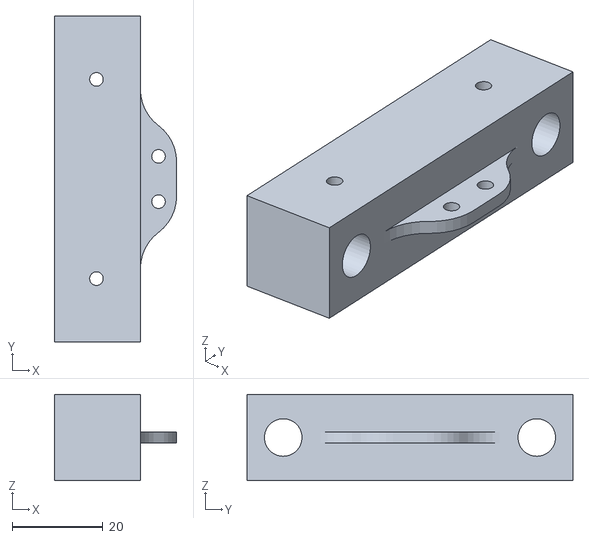
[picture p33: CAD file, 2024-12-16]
3D printed parts/New Gripper to any object/cube_part.STL
27.0 x 72.0 x 19.0

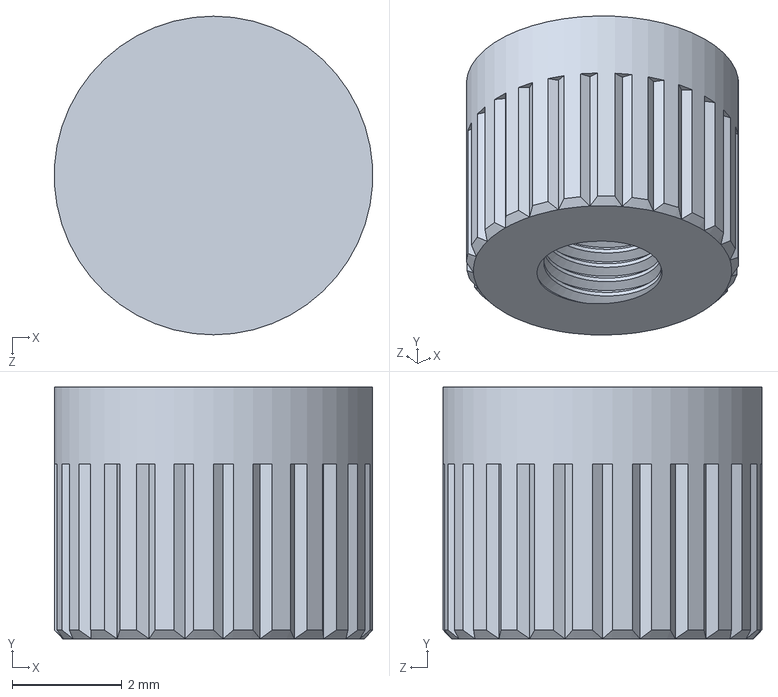
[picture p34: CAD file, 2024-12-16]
3D printed parts/mg995-servo-3.snapshot.4/Shaft.SLDPRT
5.79 x 4.58 x 5.80 mm

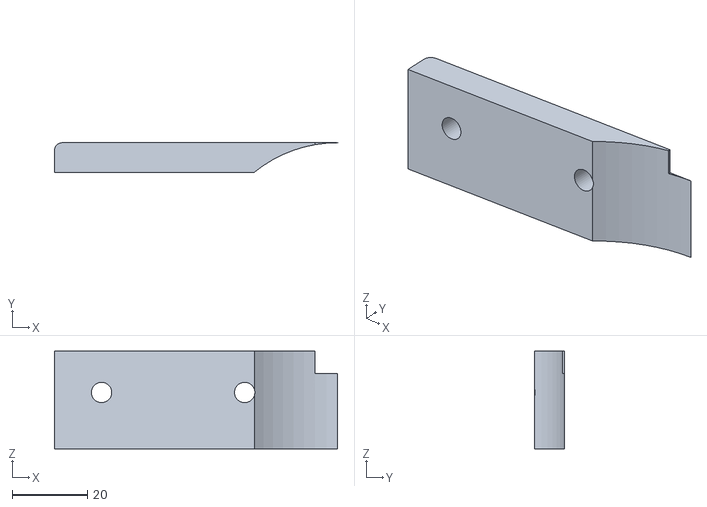
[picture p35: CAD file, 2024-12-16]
3D printed parts/Z-axisGearbox.STL
75.2 x 7.85 x 26.0

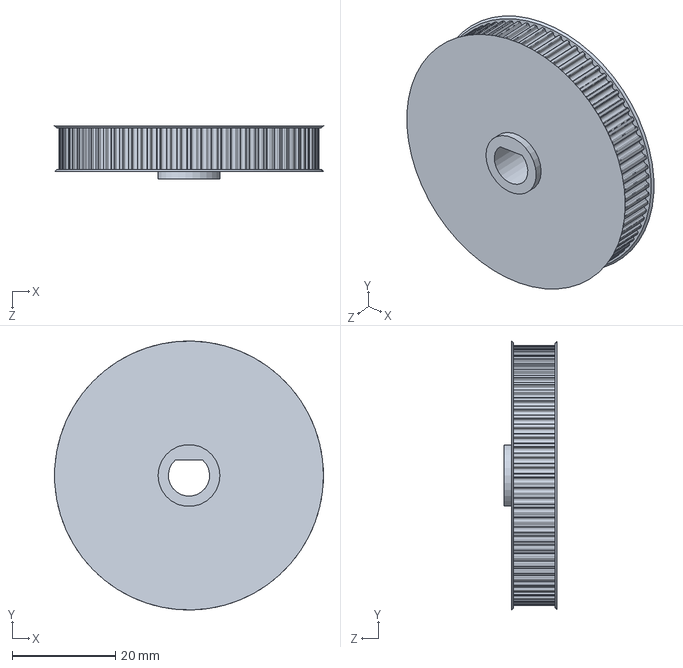
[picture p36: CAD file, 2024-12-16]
3D printed parts/GT2_80t_TimingBeltPulley.SLDPRT
52.1 x 52.1 x 10.3 mm

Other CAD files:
3D printed parts/mg995-servo-3.snapshot.4/MG995 Assembly.SLDASM
3D printed parts/mg995-servo-3.snapshot.4/Wires.SLDPRT
3D printed parts/mg995-servo-3.snapshot.4/Wire Boot.SLDPRT
3D printed parts/New Gripper to any object/sideplate.STL
3D printed parts/40mmExtusionV_Wheel.SLDPRT
3D printed parts/40mmExtusionV_Wheel.STL
3D printed parts/ExtendedGT2_80t_TimingBeltPulley.STL
3D printed parts/GT2_80t_TimingBeltPulley.STL
3D printed parts/New Gripper to any object/holdcube.STL
3D printed parts/New Gripper to any object/line_seg.STL
3D printed parts/New Gripper to any object/weight_holder.SLDPRT
3D printed parts/New Gripper to any object/weight_holder.STL
3D printed parts/New Gripper to any object/weight_holder_top.STL
3D printed parts/cube_part.SLDPRT
3D printed parts/gripper_main.STL
3D printed parts/holdcube.SLDPRT
3D printed parts/mg995-servo-3.snapshot.4/MG995 Assembly.IGS
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

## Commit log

2024-12-08 Create Coordinate Frames.jpg
2024-12-14 Homing Function
    Here each motor goes to it's home position.
2024-12-15 Bill of material
2024-12-15 Metal bar
    these are metal frame pics.
2024-12-15 Metal frame pics
2024-12-15 3D printed parts
2024-12-15 Wiring pic
2024-12-15 3D printing
2024-12-16 3d Printed parts
    Here these parts that I designed for my scara robot. Here i created robot gripper that can grab any shape.
    [40mmExtusionV_Wheel.SLDPRT, 40mmExtusionV_Wheel.STL, 5to1LastSegment_top.STL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]
2024-12-16 move to home/3d printed parts
    [40mmExtusionV_Wheel.SLDPRT, 40mmExtusionV_Wheel.STL, 5to1LastSegment_top.STL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]
2024-12-16 Full arm without wiring
2024-12-16 Create Forard kinematics.png
